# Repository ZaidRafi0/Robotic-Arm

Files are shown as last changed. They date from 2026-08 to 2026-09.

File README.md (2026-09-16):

# Robotic Arm — 4-Axis Articulated Arm (Custom Design)

> A 4-DOF robotic arm designed and built from scratch — base rotation, shoulder, elbow, and wrist, plus a two-gear linkage claw gripper. 338 mm reach, servo-driven, fully 3D-printed in PLA, controlled with an inverse kinematics solver. Every joint, the base bearing, the gear train, and the actuator selection were designed around a worked torque budget rather than copied from a reference build.

**Work in progress.** Full CAD model is complete; currently printing and assembling. See [Status](#status).

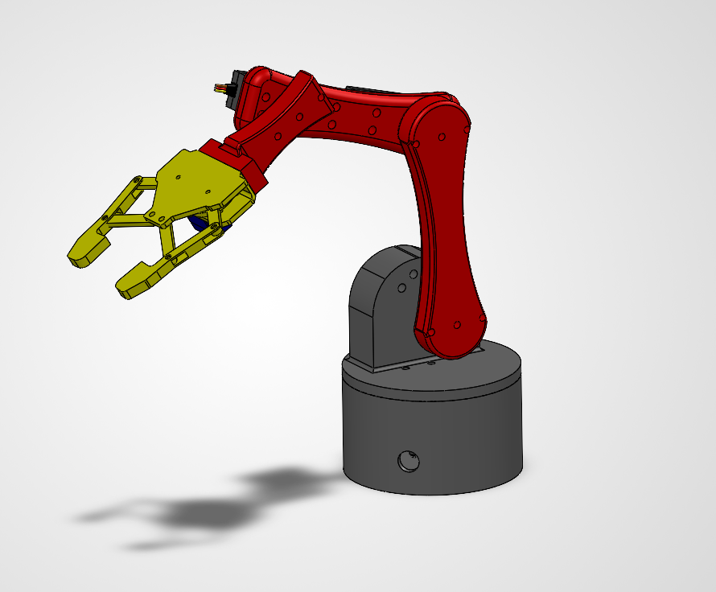
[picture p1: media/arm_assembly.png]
Robotic Arm

*Full assembly — 4-axis arm with two-gear linkage claw gripper*

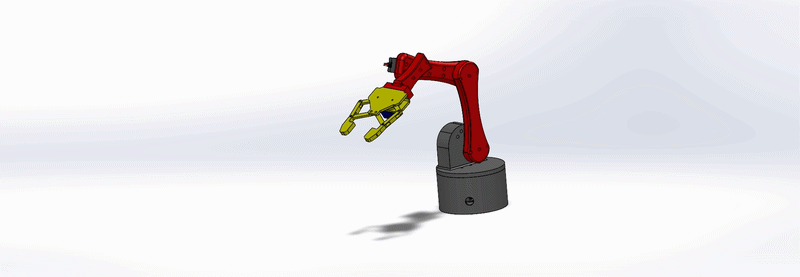
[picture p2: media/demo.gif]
Demo


## Overview

A custom 4-axis arm built around the actuators on hand: four MG996R servos and one SG90 micro servo. Rather than starting from a fixed payload/reach target, I worked backward from what those servos could actually hold — the shoulder is the binding constraint, so link lengths were sized to keep it well under the MG996R's stall torque.

Two subsystems drove most of the design work. The **base rotation joint** carries the full weight and tipping moment of the arm on a dedicated bearing surface rather than on the servo's output shaft, which is rated for torque only. The **gripper** went through a full redesign — from a double rack-and-pinion to a two-gear linkage claw — after the rack version proved to depend on hardware that wasn't available.

## Status

Full CAD model complete. Currently printing and assembling.

| Part | Design | Printed |
|---|---|---|
| Base | Complete | Yes |
| Shoulder bracket | Complete | Yes |
| Upper arm | Complete | Yes |
| Forearm | Complete | Yes |
| Wrist bracket | Complete | Pending |
| Gripper — gears, arms, links, housing | Complete | In progress |

**Remaining work:**

1. Print and assemble the remaining parts; iterate on fits (see [What broke](#what-broke)).
2. Wire the arm: five servos to a PCA9685, separate 5-6 V supply, common ground.
3. Write and tune the inverse kinematics solver.
4. Measure as-built payload, grip force, and repeatability.

## Specs

| Property | Value |
|---|---|
| Degrees of freedom | 4 (base, shoulder, elbow, wrist) + gripper |
| Upper arm (shoulder to elbow) | 110 mm |
| Forearm (elbow to wrist) | 95 mm |
| Working reach | 338 mm to grasp point |
| Design payload | 75 g at full extension |
| Shoulder holding torque (worst case) | 6.44 kg·cm — 59% of MG996R stall |
| Jaw opening | 49 mm |
| Printed structure mass | ~107 g |
| Total arm mass (printed + servos) | ~256 g |
| Material | PLA throughout |

## Torque budget

The arm was sized from this rather than the other way around. Worst case is the arm held horizontal at full extension; every mass contributes a moment at the shoulder proportional to its distance from the pivot. Masses are as-sliced (4 walls, 30% infill), which is conservative — the links print at 15%.

| Item | Mass | Distance from shoulder | Moment |
|---|---|---|---|
| Upper arm | 30.2 g | 5.5 cm | 0.17 kg·cm |
| Elbow servo | 55 g | 11.0 cm | 0.61 |
| Forearm | 31.0 g | 15.4 cm | 0.48 |
| Wrist servo | 55 g | 20.5 cm | 1.13 |
| Wrist bracket | 18.2 g | 22.0 cm | 0.40 |
| Gripper assembly + SG90 | 27 g | 30.0 cm | 0.81 |
| Fasteners and hardware | ~20 g | ~15.0 cm | 0.30 |
| Payload | 75 g | 33.8 cm | 2.54 |
| **Shoulder total** | | | **6.44 kg·cm** |

This is a **static** budget — the torque required to hold position at full extension. Accelerating the arm demands more momentarily, which is what the 41% margin to stall absorbs.

## FEA — shoulder bracket

The shoulder bracket is the highest-stress printed part, so it was analyzed against the load derived above rather than an assumed one.

- **Setup:** static study, custom PLA material, fixed at the base flange (its bolted interface), loaded at the servo bore with 2.5 N vertical and 0.63 N·m (the 6.44 kg·cm moment in SI).

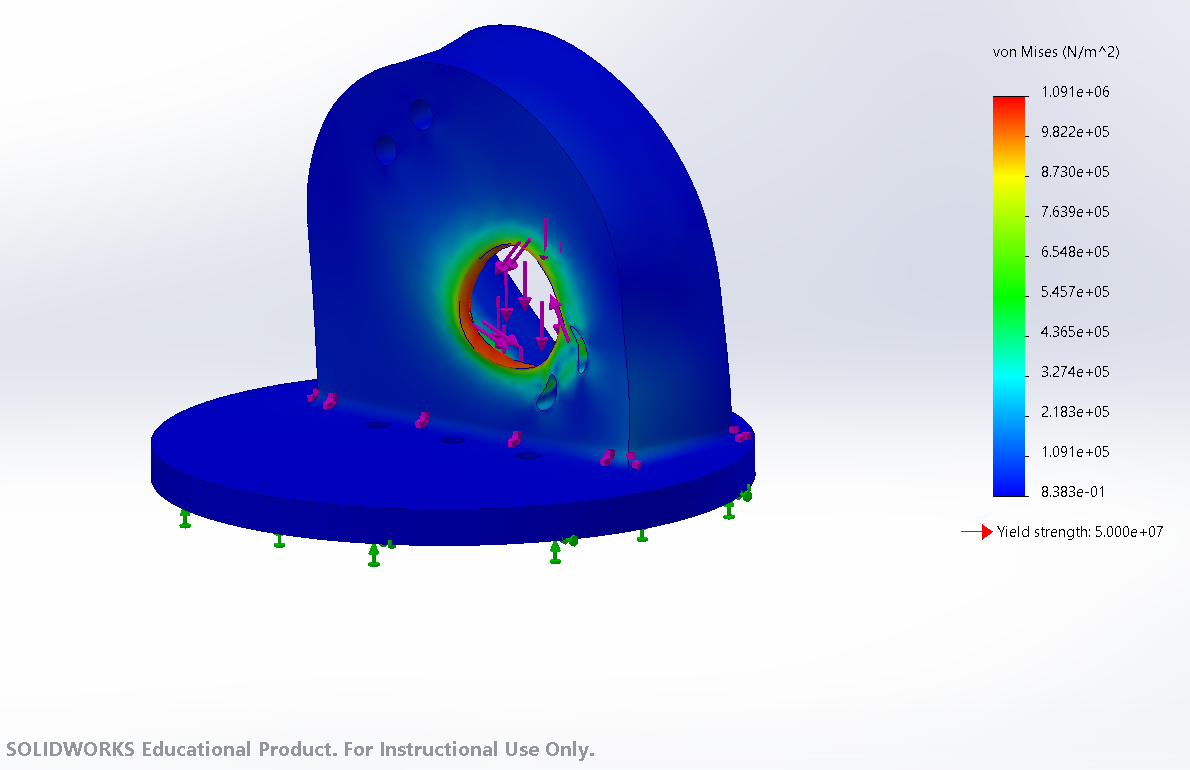
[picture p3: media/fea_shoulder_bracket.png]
FEA — shoulder bracket

*Von Mises stress under the calculated load case. Peak stress at the servo bore; gusset roots near zero.*

- **Result:** peak von Mises stress of 1.09 MPa against PLA's 50 MPa yield — a factor of safety of roughly 46.
- **Finding:** stress at the gusset roots and the wall-to-base fillet is near zero, indicating the gussets carry the bending load as intended. The only concentration is local bearing where the load enters the bore, which is a different failure mode than the wall bending the gussets were added to prevent.
- **Limitation:** the model assumes isotropic bulk PLA. Printed parts are anisotropic — layer adhesion runs roughly 50-70% of in-plane strength — so the as-built factor of safety across layer lines is lower than reported.

## Design decisions

| Decision | Why | Result |
|---|---|---|
| 4-DOF all-servo layout (SG90 gripper + 4x MG996R) | Designed around available actuators; shoulder torque fits an MG996R at this reach and payload | Working arm without sourcing steppers |
| Link lengths sized from the shoulder torque budget | Shoulder holding the arm horizontal is the binding load | 6.44 kg·cm worst case, 41% margin to stall |
| SG90 at the gripper instead of an MG996R | Saves ~46 g at the far end of the arm, the worst place for weight | Lower shoulder torque for free |
| Rotation load on a bearing surface, not the servo shaft | Servo spline is rated for torque, not the arm's weight + tipping moment | Eliminates base wobble; servo drives rotation only |
| Rim-supported platform + center hold-down pin | Arm's center of mass sits outside the support rim, so an unpinned platform would lift and rock when extended | Rim takes weight, pin resists tipping — stable at full reach |
| Slotted horn coupling holes | The bearing should locate the platform; rigidly bolting the horn fights it and side-loads the servo | Horn transmits torque while floating radially — no binding |
| Border-frame construction on both links | Perimeter material carries the bending; hollow center saves mass out on the lever arm | Links came in at ~30 g each |
| Two-gear linkage claw over the earlier rack-and-pinion gripper | The rack design depended on smooth low-friction rails; printed plastic channels bind, and metal linear rails weren't available | A gripper built entirely from printable parts, with no sliding fits — and significantly lighter at the arm's longest lever |
| Equal-size meshing gear sectors, one driven by the servo | Meshed gears counter-rotate, so a single actuator drives both claw arms symmetrically | Both jaws close at the same rate, centering the object |
| Teeth cut only over the arc the arms sweep | The arms travel well under a full rotation, so teeth elsewhere are dead material | Less print time and material with no loss of function |
| Gussets on the shoulder bracket wall | The wall is a cantilever; arm weight tries to fold it at its root | FEA confirms near-zero stress at the gusset roots |

## Actuators & BOM

| Joint | Actuator | Notes |
|---|---|---|
| Base rotation | MG996R | Drives rotation only; load carried by the base bearing |
| Shoulder | MG996R | Binding torque constraint — sets the reach/payload limit |
| Elbow | MG996R | |
| Wrist | MG996R | Single axis (pitch) |
| Gripper | SG90 | Drives one gear sector through its horn |
| Controller | Arduino Uno + PCA9685 | PCA9685 drives all 5 servos over I2C |
| Power | Separate 5-6 V, 3 A+ supply | Common ground with the Arduino; never powered off the board |
| Fasteners | M3 bolts, nuts and washers; M2 at the gripper | Nyloc nuts at vibration-loaded joints |

## Gripper

A two-gear linkage claw driven by the SG90.

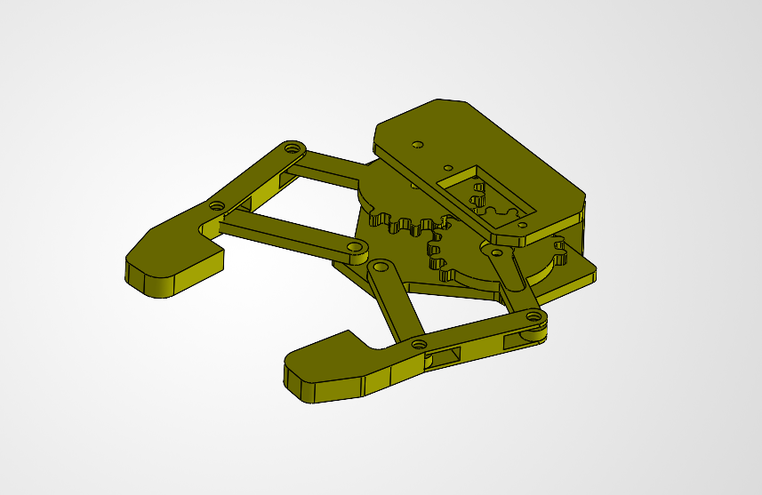
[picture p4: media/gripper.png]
Gripper

*Two-gear linkage claw — meshing gear sectors drive both claw arms from a single SG90*

- Two meshing gear sectors of equal size sit side by side, so driving one rotates the other in the opposite direction at the same rate. The SG90 drives one through its horn.
- Each gear carries a claw arm, and each arm is tied to a link, so the two arms open and close in mirror. Symmetric motion centers the object between the jaws rather than pushing it to one side.
- Equal gear sizes give a 1:1 ratio, so both arms sweep the same angle for a given servo input.
- Teeth are cut only over the arc the arms actually travel — a gear sector rather than a full gear.
- Jaw opening: 49 mm.

Because the arms pivot on the gear axes, the jaw faces tilt as they close — this grips like pliers rather than clamping flat. Parallel closing was a property of the earlier rack design that was traded away for printability.

## Control

Five servos driven from a PCA9685 over I2C, commanded by an Arduino Uno. Target end-effector positions are resolved to joint angles by an inverse kinematics solver rather than commanding each joint by hand — the base handles yaw, and the shoulder, elbow, and wrist solve as a planar chain within the plane the base points at.

## Print settings

All PLA.

| Part | Walls | Infill |
|---|---|---|
| Base | 4 | 30% gyroid |
| Rotating platform | 4 | ribbed (solid rim and hub) |
| Shoulder bracket | 4 | 30% gyroid |
| Upper arm | 4 | 15% |
| Forearm | 3 | 15% |
| Wrist bracket | 4 | 25-30% |
| Gripper housing | 4 | 20% |
| Gear sectors | 4 | 40%+ |
| Claw arms | 4 | 40-50% |
| Links | 4 | 50%+ |

Two rules used throughout: **walls carry load, infill fills space** — perimeters go up before infill on anything that feels weak. And **print orientation beats every other setting** — links flat along their length, gear teeth in-plane rather than stacked as layer edges.

## What broke

**Modeled clearances don't survive contact with the printer.** The recurring lesson of this build: gaps and fits come out tighter than modeled, because extruded plastic spreads slightly and layer lines encroach on nominal dimensions. Three instances so far:

- The claw arm's 3 mm center gap prints under 3 mm — layer lines intrude into the opening, closing it up enough to interfere. Needs to be opened up in CAD to land at 3 mm as printed.
- The SG90 push-fit pocket in the gripper housing came out too tight.
- On the earlier rack-and-pinion gripper, the rack channels and pinion pocket were both too tight to move freely.

The fix in every case is the same: model the clearance larger than the target, and print a test coupon of any fit before committing to a full part.

**Sliding fits in printed plastic were the wrong approach for the gripper.** The original design used two racks sliding in channels on opposite sides of a driven pinion. In practice the printed channels bound against the racks. Opening the clearances would have traded binding for backlash — the design really wanted metal linear rails, which weren't available. Rather than tune a fit that was fighting the process, I replaced the mechanism with a two-gear linkage claw, which achieves symmetric jaw motion using only rotating joints and no sliding surfaces. It also came out considerably lighter, which bought back shoulder torque margin at the longest lever on the arm.

**The wrist bracket was too short** in its first revision — the gripper couldn't clear the forearm through the full pitch range. Lengthened, with the final dimension set by the clearance check rather than chosen.

## v2 ideas

Brainstorms collected while researching, not committed work:

- **NEMA17 stepper motors** in place of hobby servos, for true repeatability and higher payload.
- **Cycloidal gearboxes** at the major joints — a cycloidal reducer trades motor speed for torque in a single high-ratio stage with very low backlash, which should give smoother motion than servo-grade positioning allows.

## License

MIT — see [LICENSE](LICENSE).

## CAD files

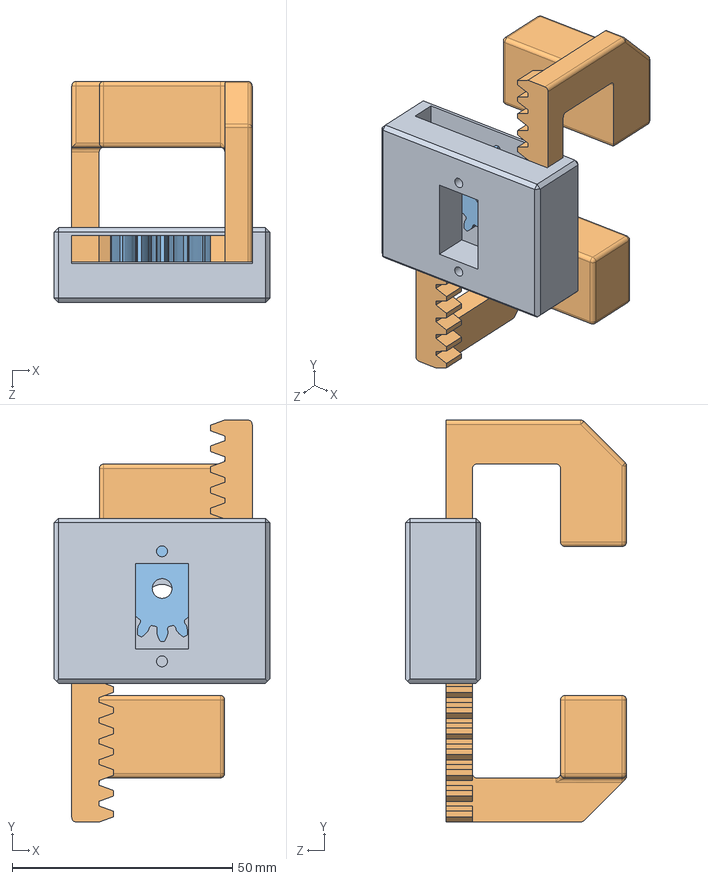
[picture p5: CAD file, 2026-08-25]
cad/gripper_assembly.SLDASM
49.0 x 91.3 x 50.2 mm
pinion
rack x 2
pinion_rack_housing

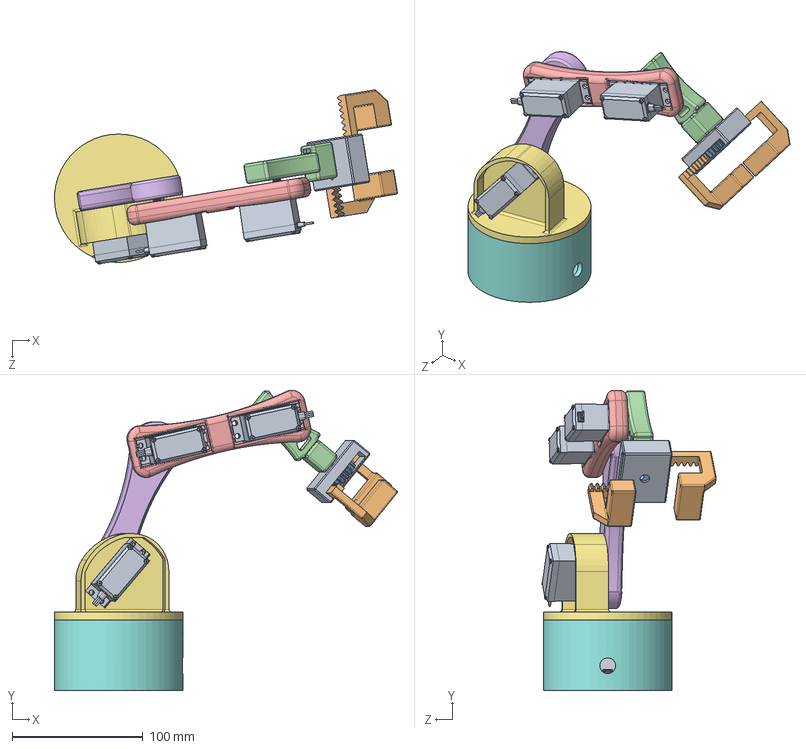
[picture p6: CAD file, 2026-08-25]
cad/robot_arm_assembly.SLDASM
262.0 x 229.3 x 133.1 mm
MG996R_CAD_FILE x 4
robot_arm_base_v2
base_joint
arm_link_1
arm_link_2
wrist
pinion
rack x 2
pinion_rack_housing

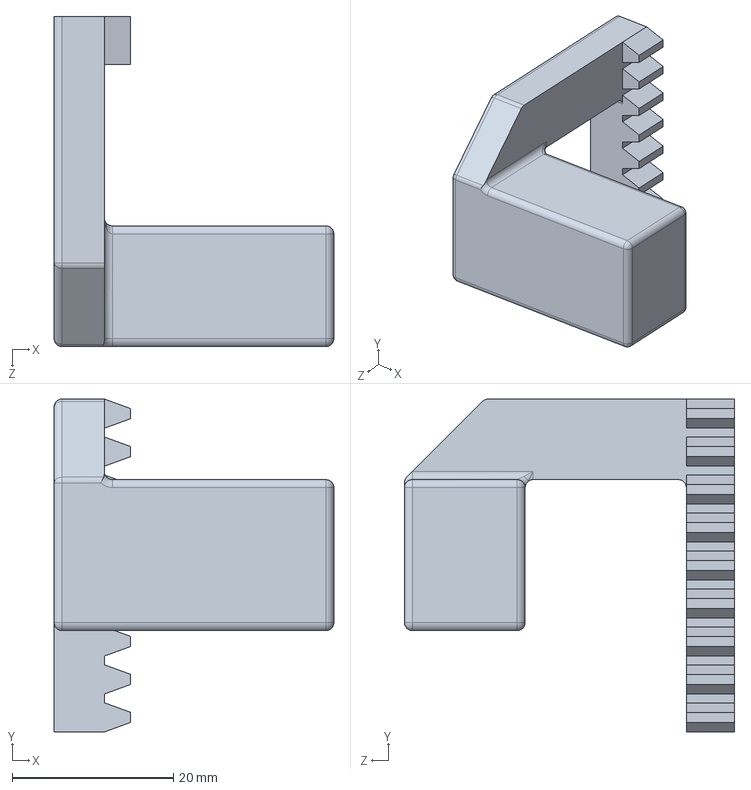
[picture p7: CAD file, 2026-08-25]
cad/rack.SLDPRT
34.7 x 41.3 x 41.0 mm

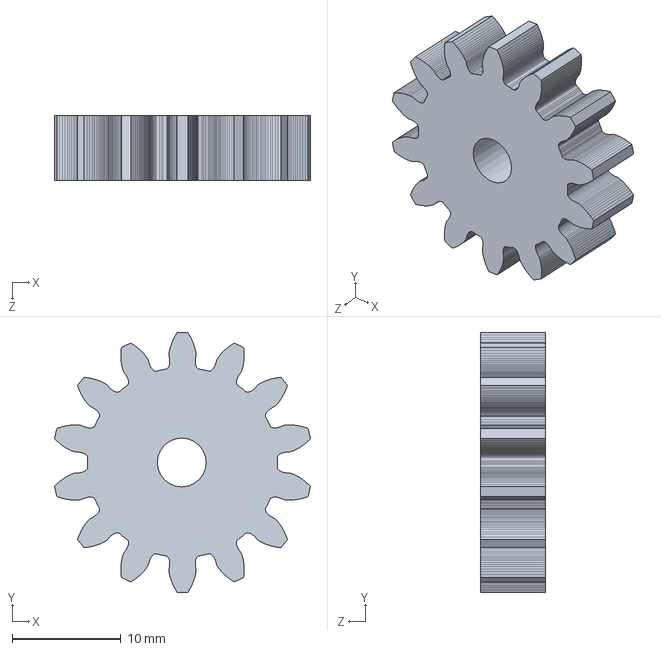
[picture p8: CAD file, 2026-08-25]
cad/pinion.SLDPRT
23.6 x 24.0 x 6.00 mm

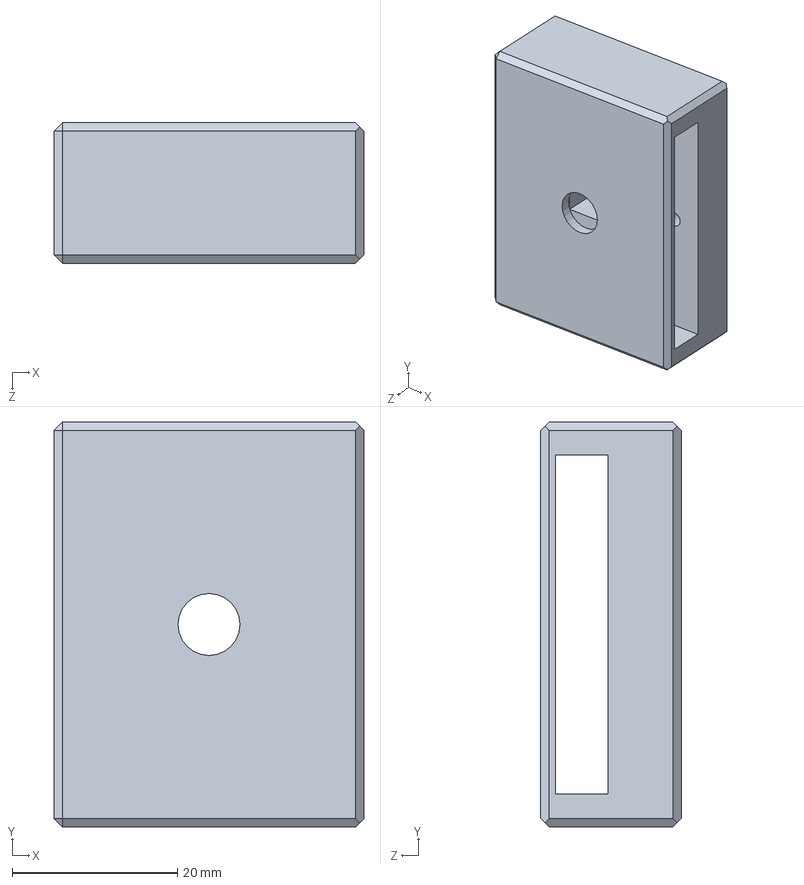
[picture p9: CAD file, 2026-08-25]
cad/pinion_rack_housing.SLDPRT
37.5 x 49.0 x 17.0 mm

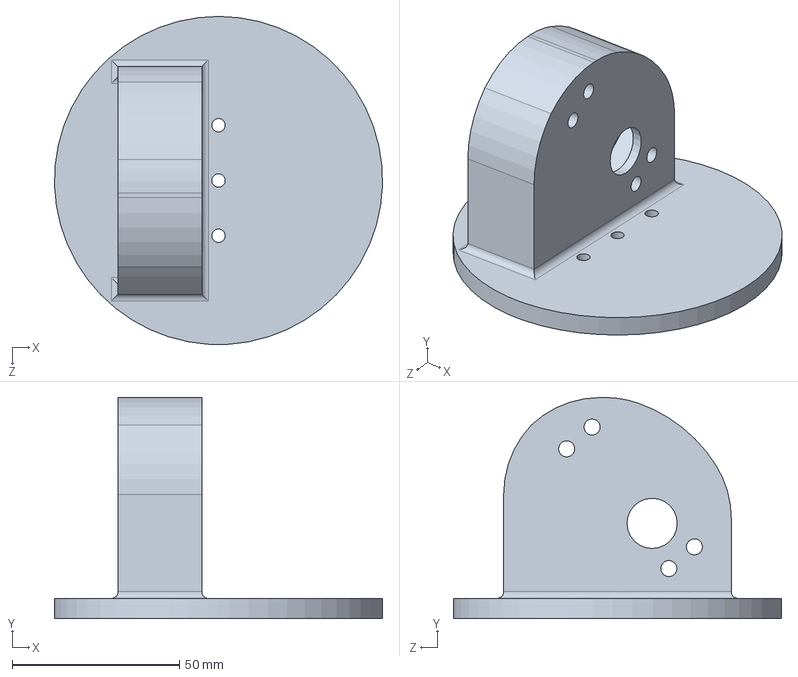
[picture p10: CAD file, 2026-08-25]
cad/base_joint.SLDPRT
98.0 x 66.0 x 98.0 mm

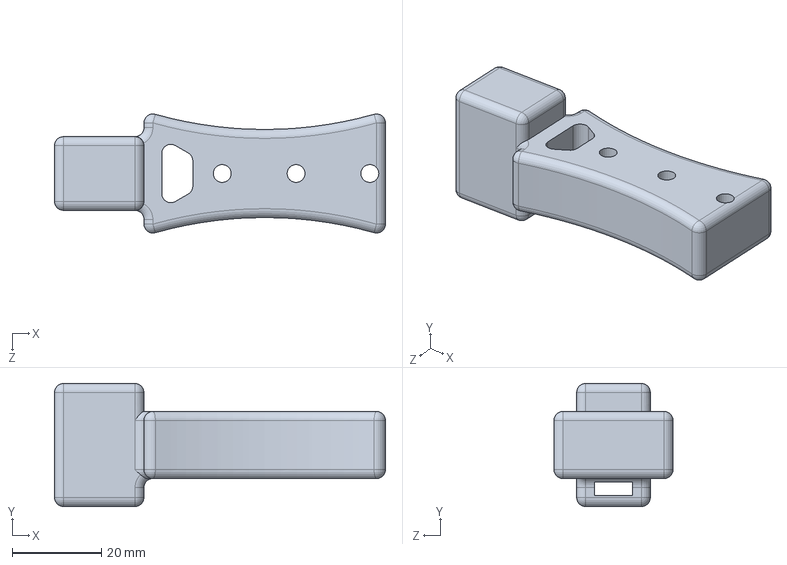
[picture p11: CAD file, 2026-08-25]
cad/wrist.SLDPRT
74.0 x 27.5 x 26.6 mm

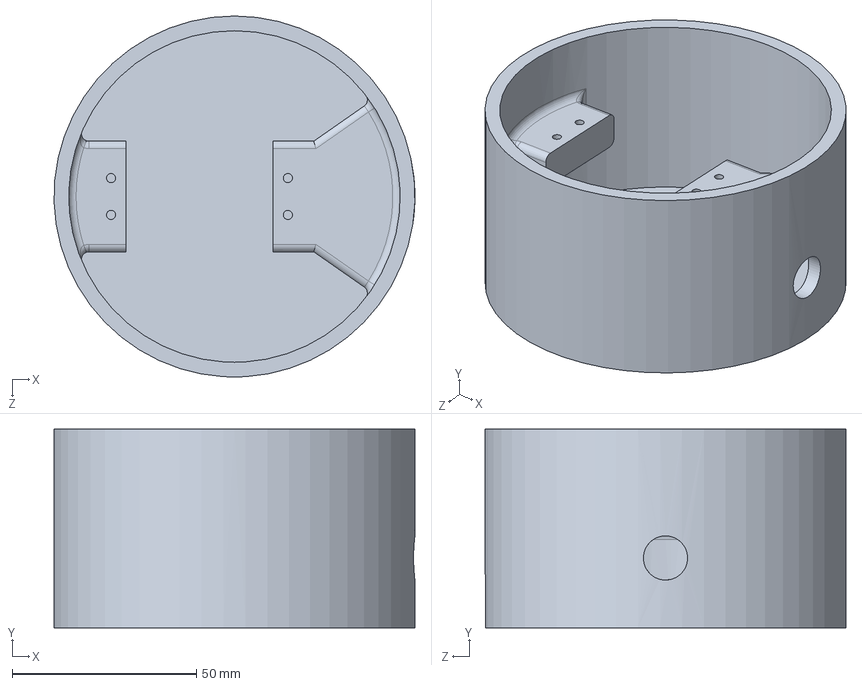
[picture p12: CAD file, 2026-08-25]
cad/robot_arm_base_v2.SLDPRT
98.0 x 54.0 x 98.0 mm

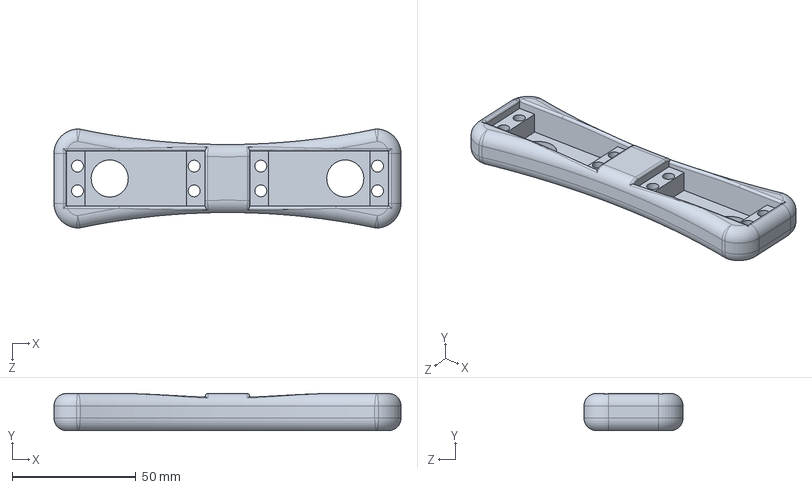
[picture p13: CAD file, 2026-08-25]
cad/arm_link_2.SLDPRT
140.0 x 15.0 x 39.9 mm

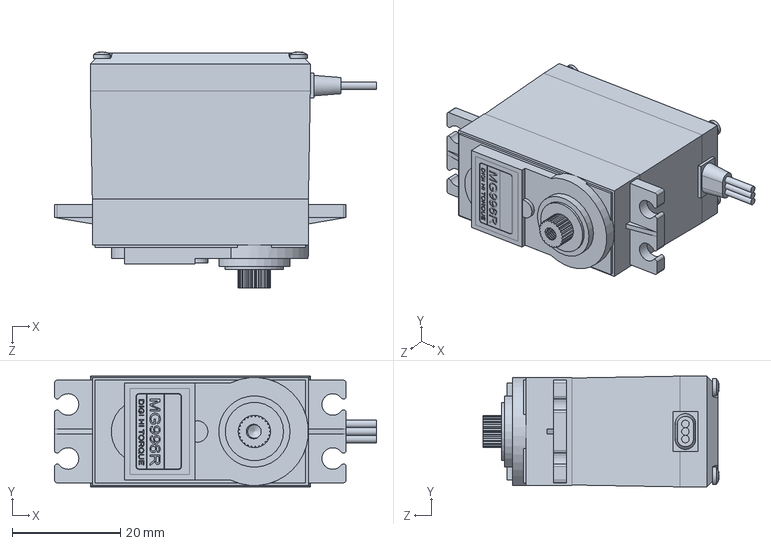
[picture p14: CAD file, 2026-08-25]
cad/MG996R_CAD_FILE.SLDPRT
59.6 x 20.5 x 43.8 mm

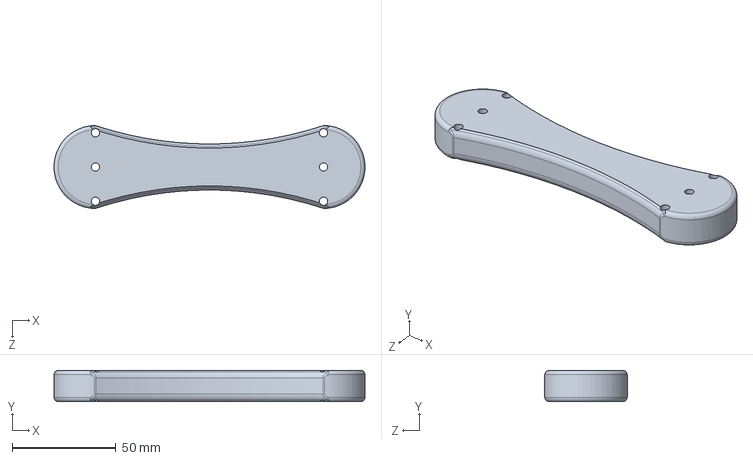
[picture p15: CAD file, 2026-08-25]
cad/arm_link_1.SLDPRT
150.0 x 15.0 x 40.0 mm
